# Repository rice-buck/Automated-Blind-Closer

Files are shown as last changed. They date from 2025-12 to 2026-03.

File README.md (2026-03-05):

# SmartBlinds-ESP32

An automated, IoT-connected blind opener and closer built with an **ESP32**, **A4988 stepper driver**, and **Alexa integration**.

This project transforms standard manual blinds into a smart home asset, allowing for control via a physical hardware button, a mobile app, or Alexa voice commands.

---

## Features

* **Voice Control:** Fully integrated with Amazon Alexa via the SinricPro platform.
* **Mobile Dashboard:** Remote toggle capability from any smartphone via the SinricPro app.
* **Smooth Motion Logic:** Custom C++ implementation featuring linear acceleration and deceleration ramps to reduce mechanical stress on the blind's header rail.
* **Manual Override:** A physical hardware button allows for instant local control without needing a phone or voice.
* **Cloud Sync:** Real-time state synchronization; if you press the physical button, the Alexa app updates the blind status automatically.

---

##  Hardware Needed

* **Microcontroller:** ESP32 (NodeMCU Dev Kit).
* **Motor Driver:** A4988 Stepper Motor Driver.
* **Actuator:** NEMA 17 Stepper Motor.
* **Power Supply:** Dual-rail setup (12V for motor VMOT, 5V via Micro-USB for ESP32 VIN).
* **Stability Components:** 470µF electrolytic decoupling capacitor on the VIN rail to handle Wi-Fi current spikes (~250mA) and prevent brownout resets.

---

## Firmware Overview

The firmware is written in C++ using the Arduino framework, utilizing an **event-driven architecture** rather than simple polling for cloud commands.

### Key Technical Concepts:
* **Asynchronous Callbacks:** Uses `onPowerState` hooks to trigger motor movement immediately upon receiving a cloud packet.
* **Watchdog Maintenance:** The `openCloseRotate2()` function explicitly calls `SinricPro.handle()` during the step loop to prevent the WebSocket connection from timing out during long rotations.
* **Power Management:** Utilizes the A4988 `ENABLE` pin to depower the motor coils when stationary, preventing overheating and saving energy.

### Pin Configuration
| Component | ESP32 GPIO |
| :--- | :--- |
| **Step** | 18 |
| **Direction** | 19 |
| **Enable** | 21 |
| **Button** | 23 |

---

## Installation & Setup

1.  **Library Installation:** Open the Arduino Library Manager and install `SinricPro`, `ArduinoJson`, and `WebSockets`.
2.  **Cloud Configuration:** * Create a free account at [Sinric.pro](https://sinric.pro).
    * Add a "Switch" or "Blinds" device to generate your `APP_KEY`, `APP_SECRET`, and `DEVICE_ID`.
3.  **Alexa Integration:** * Enable the **Sinric Pro** skill in the Alexa app.
    * Link your account and "Discover Devices".
4.  **Deployment:** Update the Wi-Fi and SinricPro credentials in `BlindControlV2.ino` and upload to your ESP32.

---

## Some Troubles I had
During development, I encountered the **ESP32 Brownout Detector** trigger probably due to excessive current draw on boot up. The following hardware mitigations are recommended:
* **Direct VIN Power:** Avoid powering high-draw peripherals from the ESP32's 3.3V regulator; use the `VIN` pin to tap directly into the 5V USB source.
* **Decoupling:** Place a 100µF–470µF capacitor as close to the ESP32 power pins as possible.
* **Common Ground:** Ensure the 12V motor ground and 5V logic ground are tied together to maintain a consistent reference for the `STEP` and `DIR` signals.

---

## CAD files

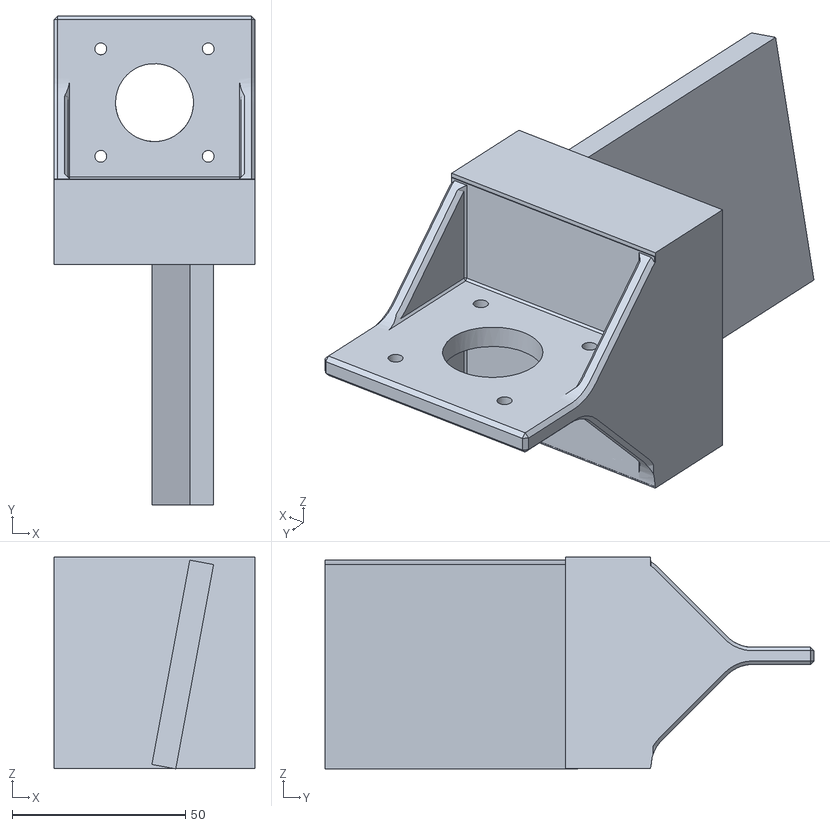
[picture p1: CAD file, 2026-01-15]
WallMount V4.stl
58.0 x 141.2 x 61.1

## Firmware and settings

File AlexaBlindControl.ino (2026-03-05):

#include <WiFi.h>
#include <SinricPro.h>
#include <SinricProSwitch.h> 


// --- Fill in your credentials here ---
#define WIFI_SSID         "Buckeye Home"
#define WIFI_PASS         "BuckeyeHomeEst2013"
#define APP_KEY           "6e937133-51cd-48d1-a77e-13bb88c02884"
#define APP_SECRET        "46f1fde3-5949-4986-9770-bf337407cef4-6680d578-8ed0-4428-84d8-98a5acc33161"
#define SWITCH_ID         "69954ef05987ba9b0604bfb0"

// --- Hardware Pins ---
#define STEP_PIN 18
#define DIR_PIN 19
#define ENABLE_PIN 21
#define BUTTON_PIN 23
#define LDR_PIN 34

// --- Motor & Logic Constants ---
const int stepsPerRevolution = 3200;
const int stepsToOpenClose = stepsPerRevolution * 4;
const int lightThreshold = 2500;
const int darkThreshold = 200;
const unsigned long oneHourInterval = 3600000;

// --- State Variables ---
bool isOpen = true;
bool lastButtonState = HIGH;
bool manualOverrideActive = false;
unsigned long previousMillis = 0;

// --- Alexa/App Callback ---
// This function runs when you toggle the button on your phone or talk to Alexa
bool onPowerState(const String &deviceId, bool &state) {
  Serial.printf("Request received: %s\n", state ? "Open" : "Close");
  
  if (state != isOpen) {
    openCloseRotate2();
    previousMillis = millis(); // Treat Alexa command as a manual override
    manualOverrideActive = true;
  }
  return true; 
}

void setup() {

  Serial.begin(115200);

  pinMode(STEP_PIN, OUTPUT);
  pinMode(DIR_PIN, OUTPUT);
  pinMode(ENABLE_PIN, OUTPUT);
  pinMode(BUTTON_PIN, INPUT_PULLUP);
  pinMode(LDR_PIN, INPUT);
  
  digitalWrite(ENABLE_PIN, HIGH); // Start with motor driver disabled (off)
  
  // Connect to Wi-Fi
  WiFi.begin(WIFI_SSID, WIFI_PASS);
  Serial.print("Connecting to WiFi");
  while (WiFi.status() != WL_CONNECTED) {
    Serial.print(".");
    delay(500);
  }
  Serial.println(" Connected!");

  // Initialize SinricPro
  SinricProSwitch &mySwitch = SinricPro[SWITCH_ID];
  mySwitch.onPowerState(onPowerState);
  SinricPro.begin(APP_KEY, APP_SECRET);
  
  Serial.println("Setup complete and connected to SinricPro");
}

void loop() {
  // Keeps the connection to Alexa/Phone alive
  SinricPro.handle(); 

  // Create a reference so the compiler knows this is a Switch device
  SinricProSwitch &mySwitch = SinricPro[SWITCH_ID];

  int lightValue = analogRead(LDR_PIN);
  bool buttonState = digitalRead(BUTTON_PIN);

  // 1. Physical Button Logic
  if (lastButtonState == HIGH && buttonState == LOW) {
    Serial.println("Manual physical toggle");
    openCloseRotate2();
    previousMillis = millis();
    manualOverrideActive = true;
    
    mySwitch.sendPowerStateEvent(isOpen);
  }
  lastButtonState = buttonState;

  // 2. Manual Override Timer
  if (manualOverrideActive && millis() - previousMillis >= oneHourInterval) {
    manualOverrideActive = false;
    Serial.println("Manual override expired. Returning to Auto (LDR) mode.");
  }

  // 3. Automatic LDR Logic (Only runs if no manual override is active)
  if (!manualOverrideActive) {
    if (lightValue < darkThreshold && isOpen) {
      Serial.println("Closing blinds for darkness");
      openCloseRotate2();
      mySwitch.sendPowerStateEvent(false); 
    } else if (lightValue > lightThreshold && !isOpen) {
      Serial.println("Opening blinds for light");
      openCloseRotate2();
      mySwitch.sendPowerStateEvent(true); 
    }
  }

  delay(10); 
}

// Function to handle the motor movement with acceleration/deceleration
void openCloseRotate2() {
  if (isOpen) {
    Serial.println("Closing Blinds...");
    digitalWrite(DIR_PIN, HIGH);
  } else {
    Serial.println("Opening Blinds...");
    digitalWrite(DIR_PIN, LOW);
  }

  digitalWrite(ENABLE_PIN, LOW); // Enable motor driver
  
  const int totalSteps = stepsToOpenClose;
  const int rampSteps = 800;
  const int startDelay = 1000;
  const int cruiseDelay = 250;

  for (int i = 0; i < totalSteps; i++) {
    int stepDelay = cruiseDelay;
    
    // Acceleration
    if (i < rampSteps) {
      stepDelay = startDelay - (startDelay - cruiseDelay) * i / rampSteps;
    } 
    // Deceleration
    else if (i > totalSteps - rampSteps) {
      stepDelay = startDelay - (startDelay - cruiseDelay) * (totalSteps - i) / rampSteps;
    }

    digitalWrite(STEP_PIN, HIGH);
    delayMicroseconds(stepDelay);
    digitalWrite(STEP_PIN, LOW);
    delayMicroseconds(stepDelay);
    
    // Feed the SinricPro watchdog every 100 steps to prevent disconnects
    if (i % 100 == 0) SinricPro.handle();
  }
  
  digitalWrite(ENABLE_PIN, HIGH); // Disable motor driver to save power/heat
  isOpen = !isOpen;
}

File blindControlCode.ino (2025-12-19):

#define STEP_PIN 18
#define DIR_PIN 19
#define ENABLE_PIN 21
#define BUTTON_PIN 23
#define LDR_PIN 34

//full step
const int stepsPerRevolution = 200;

int lightThreshold = 3000;
int darkThreshold = 1500;

bool isOpen = false;

//store what the button was last doing -- using INPUT_PULLUP --    button not pressed = HIGH      button pressed = LOW
bool lastButtonState = HIGH; //HIGH is default for pullup

unsigned long previousMillis = 0;
const unsigned long oneMinuteInterval = 60000; //one minute in milliseconds

void setup() {
  Serial.begin(115200);

  pinMode(STEP_PIN, OUTPUT);
  pinMode(DIR_PIN, OUTPUT);
  pinMode(ENABLE_PIN, OUTPUT);
  pinMode(BUTTON_PIN, INPUT_PULLUP);
  pinMode(LDR_PIN, INPUT);

  digitalWrite(ENABLE_PIN, HIGH); //motor off
  digitalWrite(DIR_PIN, HIGH); //choose direction

  Serial.println("Setup complete");
}

void loop() {

  int lightValue = analogRead(LDR_PIN);

  Serial.print("LV: ");
  Serial.println(lightValue);

  //gets state of button 
  bool buttonState = digitalRead(BUTTON_PIN);

  //looks for when button is pressed
  if (lastButtonState == HIGH && buttonState == LOW){
    Serial.println("Manual toggle");
    rotateOneRevolution();
    previousMillis = millis(); //start minute timer
  }

  lastButtonState = buttonState;

  //check if override is active
  bool manualOverride = (millis() - previousMillis) < oneMinuteInterval;

  if(!manualOverride) {
  //when its dark
  if(lightValue < darkThreshold && isOpen){
    Serial.println("Closing blinds for darkness");
    rotateOneRevolution();
  }
  //when its light
  if(lightValue > lightThreshold && !isOpen){
    Serial.println("Opening blinds for light");
    rotateOneRevolution();
    }
  } else {
    Serial.println("Maunual Override Active");
  }
  delay(300);
}

//motor retate function 
void rotateOneRevolution(){
  digitalWrite(ENABLE_PIN, LOW); //motor on
  delayMicroseconds(10);

  //check if blinds open or not and choose direction
  if(isOpen) {
    Serial.println("Closing Blinds");
    digitalWrite(DIR_PIN, LOW);
  } else {
    Serial.println("Opening Blinds");
    digitalWrite(DIR_PIN, HIGH);
  }

  delayMicroseconds(10); //give time for DIR to settle

  for (int i = 0; i < stepsPerRevolution; i++){
    //pulses for motor
    digitalWrite(STEP_PIN, HIGH);
    delayMicroseconds(1500); //smaller delay = faster motor
    digitalWrite(STEP_PIN, LOW);
    delayMicroseconds(1500);
  }
  isOpen = !isOpen; //toggles state of t/f
  digitalWrite(ENABLE_PIN, HIGH); //disable motor with enable pin to save power and stuff
}

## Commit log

2026-01-15 Wall Mount STL file added
    [WallMount V4.stl]
2026-03-05 Initialize README with project details and setup instructions
    Added detailed project description, features, hardware requirements, firmware overview, installation steps, and troubleshooting tips for SmartBlinds-ESP32.
